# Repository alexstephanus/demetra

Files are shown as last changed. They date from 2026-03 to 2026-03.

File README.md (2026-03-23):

# Demetra
Demetra is a low-cost, local-first hydroponic controller.  It manages your system's pH, nutrient, and ORP levels, runs fertigation cycles, and can keep you reservoir topped up from an external water line or tank.

It reads the following set of sensors:
 - pH
 - ORP
 - Conductivity/TDS
 - Temperature

Using these sensors and the 6 supported peristaltic dosing pumps, it keeps your reservoir in the optimal range for plant growth.  Additionally, its 4 configurable DC outlets can drive fertigation cycles, stir treatment solutions into your reservoir, or drive general-purpose outlets.  It lets us 

It's built using off-the-shelf components, and designed end-to-end for ease of assembly and operation.  You can view assembly and setup docs [here](https://alexstephanus.github.io/demetra).

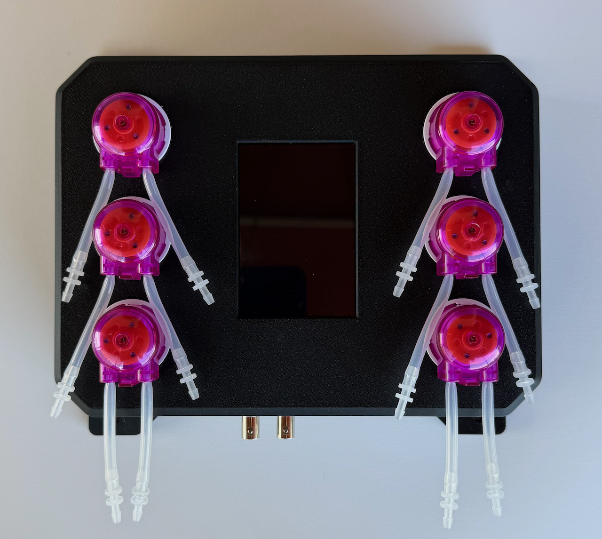
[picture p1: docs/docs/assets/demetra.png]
Here's what it looks like!


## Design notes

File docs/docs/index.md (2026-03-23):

# Demetra

You got into hydroponics because you care about what you're growing, not because you're passionate about pH and TDS levels.  Demetra takes care of that for you, freeing you up to focus on what's important: your plants.

Demetra is a low-cost, local-first, subscription-free hydroponic garden controller.
It provides hassle-free management of your system's pH, nutrient, and ORP levels.  Additionally, it can drive watering schedules and automatically top up your reservoir from a water line or external tank.
Demetra is built almost exclusively with off-the-shelf parts and components.  The parts that _are_ custom are explicitly designed to be fabricated as easily as possible:

- Motherboard:  Designed to be hand-populated, with primarily 0805 passives and SOIC-package ICs.  Any circuit board manufacturer should be able to fabricate the bare PCB, and you can populate it yourself.
- Enclosure:  240mm x 210mm x 65mm, which fits many consumer 3D printers.

<div class="grid cards" markdown>

- Demetra

</div>

## What it does

Demetra continuously monitors your system's pH, nutrient, and ORP levels, and adjusts them as needed to maintain optimal growth conditions.

Additionally, the system has 4 configurable DC outlets, which can be used for the following:

- Fertigation pumps, which run on a user-defined schedule
- Stir pumps, which are triggered to run after a treatment solution is added (e.g. pH down or nutrients), mixing your reservoir to ensure a tight feedback loop
- Solenoid valves, which can be used in conjunction with the water-level sensor to top up your reservoir from a water line
- General-purpose outlets, which are scheduled like fertigation pumps

Its local-first UI means that you can configure it using the onboard screen, no need for a subscription.

## What it doesn't do

Demetra's primary focus is reservoir control and fertigation management.  It does not try to do:

  - Plant health monitoring: It should free you up to pay more attention to your plants, but it won't do that for you.
  - Lighting, humidity, or other environmental control.  You could theoretically get by using general-purpose outlets and an external relay, but that's out of Demetra's wheelhouse.
  - Reservoir temperature control: Demetra does monitor your reservoir's temperature, but it uses that information to control your reservoir's pH and nutrient levels.

## Building it

For more information on how to build this project, see the [build guide](build_guide/what_you_need.md).
Outside of PCB assembly and enclosure printing time, assembly and initial setup should take a few hours.

## Cost

It costs about $400 to build, excluding sensors.

- Motherboard: $230: $100 shipped for fabrication of the bare PCB from JLCPCB, $130 for components from digikey (other suppliers might charge different prices).
- Enclosure: 500g of your chosen filament (call it $10), and heat-set inserts (~$10 for a set on Amazon, less from AliExpress)
- Peristaltic pumps: $80 shipped for 6 off of AliExpress, and JST pigtails are cheap if you throw in that order as well.
- Screen: $20 from either Amazon or AliExpress
- Sensors: Budget-dependent, on the low end you're looking at $20 for a pH probe, $20 for a conductivity probe, $30 for an ORP probe, and $5 for a 10k NTC thermistor.

Links to specific parts can be found in [What You Need](build_guide/what_you_need.md#part-purchase-links).

## Roadmap:
There are some features that currently have hardware support, but aren't handled yet on the software side:

- [ ] Plumb the external Digital I/O pin through in software to allow monitoring of an external flood sensor.  
- [ ] External I2C integration to ingest data from miscellaneous sensors.  The hardware configuration has been confirmed to work, but there isn't currently software support for using it.
- [ ] WiFi and MQTT support.  The ESP32 hardware supports this, but it's not yet built out.  This would allow for remote configuration and monitoring, as well as the ability to set up healthchecks, dashboards, and notifications on warnings and errors.
- [ ] Support for multiple treatment solutions of the same type, .
- [ ] The CAN and RS485 hardware is currently totally untested.

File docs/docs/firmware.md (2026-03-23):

# Firmware

## Overview

Demetra's firmware is written in Rust, targeting the ESP32-S3 microcontroller. It uses the ESP-HAL ecosystem with the Embassy async runtime, and a Slint-based GUI for the touchscreen display.

The firmware source lives in the `firmware/` directory of the repository, organized as a Cargo workspace:

- **`chip/`** — the main ESP32-S3 application that runs on hardware
- **`lib/`** — shared business logic and UI components, testable on a host machine
- **`simulation/`** — a desktop simulation of the UI (no hardware required)

## Try the UI (No Toolchain Required)

If you just want to see the interface, you can run the simulation in Docker:

```bash
cd firmware
docker build -f Dockerfile.sim -t demetra-sim .
docker run --rm -p 6080:6080 demetra-sim
```

Then open [http://localhost:6080/vnc.html](http://localhost:6080/vnc.html) in your browser.

## Toolchain Setup

To build and flash the firmware onto an ESP32-S3, you'll need the Rust ESP toolchain.

### 1. Install Rust

If you don't already have Rust installed, you can go to the [rust-lang installation instructions](https://rust-lang.org/tools/install/) and follow the installation instructions.

This project also uses the standard nightly toolchain for host-side builds (tests, simulation), you can install it :

```bash
rustup install nightly
rustup component add rust-src --toolchain nightly
```

### 2. Install the ESP Toolchain

`espup` manages rust's the `esp` toolchain, which includes the custom LLVM backend needed for the ESP32-S3's Xtensa architecture.
To set that up, head to [the espup repository](https://github.com/esp-rs/espup) and follow the installation instructions.

### 3. Install espflash

[espflash](https://github.com/esp-rs/espflash/blob/main/espflash/README.md) is used to flash firmware onto the board and open a serial monitor.

## Building & Flashing

Connect the ESP32-S3 board via USB (J52) or a UART converter (J51), then, from inside the project's root directory, run:

The USB connection does _not_ supply power to the board, so if you're flashing using a USB cable, you'll need to plug in the power supply as well.

```bash
cd firmware
cargo +esp flash-chip
```

This builds the firmware in release mode and flashes it to the connected board.

### Other Useful Commands

```bash
# Build without flashing
cargo +esp build-chip-release

# Check for compilation errors (faster than a full build)
cargo +esp check-chip

# Run unit tests (host machine, no hardware needed)
cargo unit-test

# Run the desktop simulation outside of Docker (this will just pop up a window with the simulated UI)
cargo sim
```

## After Flashing

Once the firmware is flashed, head over to [Setup](build_guide/setup.md) for initial configuration, sensor calibration, and pump setup.

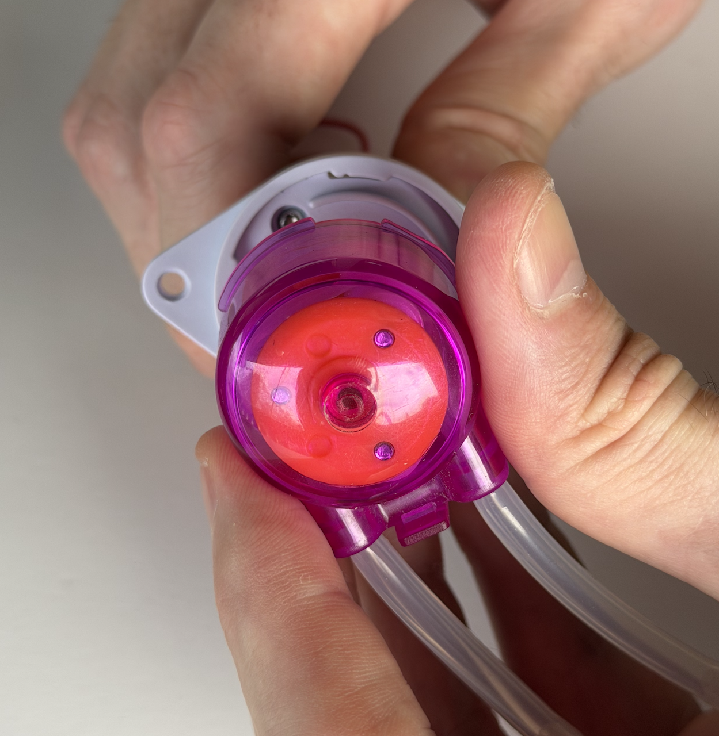
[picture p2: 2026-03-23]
docs/docs/assets/pump_mid_head_removal.png

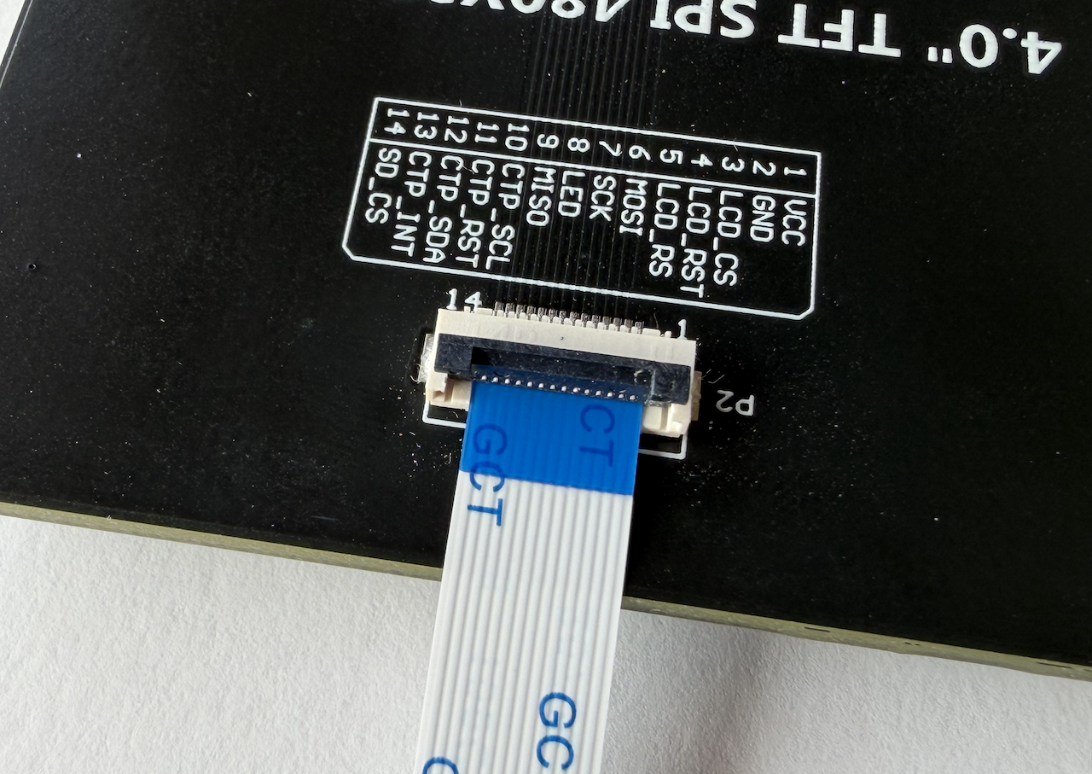
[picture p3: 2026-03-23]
docs/docs/assets/screen_cable_unlocked.png

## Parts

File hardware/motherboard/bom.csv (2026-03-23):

Reference | Value | DNP | Manufacturer_Part_Number
J51,J53,J54,J56,J201,JP51,JP52,TP1,TP2,TP3,TP4,TP5,TP6,TP7,TP8 | -- mixed values --
J52 | USB_B_Micro |  | 1051330011
C153 | 470u |  | 865080562016
C104,C105,C106,C107 | 1n |  | 885012207060
C27,C36,C45 | 1u |  | 12063C105KAT2A
C24,C28,C33,C37,C42,C46 | 1n |  | 12065C102KAT2A
U103 | ADS1015IDGS |  | ADS1015IDGSR
U13,U14,U15 | AMC3336 |  | AMC3336DWER
U152 | 3V3 Switching Reg |  | AP63203WU-7
J101,J102,J103,J104,J105,J106 | JST |  | B2B-XH-A
B201 | BH-25C-1 |  | BH-25C-1
C25,C26,C34,C35,C43,C44 | 1n |  | C0603C102K5RACTU
C10,C12,C13,C14,C17,C19,C23,C29,C32,C38,C41,C47 | 100n |  | C0603C104K5RACAUTO
C205,C206 | 4.7p |  | C0805C479D3HACTU
C151 | 22u |  | C2012X5R1V226M125AC
C21,C30,C39 | 100n |  | C3216NP01H104J160AA
R120,R123,R126,R129 | 0.02 |  | CFN1206-FX-R020ELF
C22,C31,C40 | 1u |  | CGA3E1X7R1E105K080AC
C53,C157,C159,C160,C202 | 22u |  | CL21A226MQQNNNG
C1,C2,C3,C4,C5,C6,C7,C8,C9,C11,C15,C16,C18,C20,C51,C52,C54,C101,C102,C103,C108,C109,C111,C112,C114,C152,C154,C155,C158,C201,C203,C204 | 100n |  | CL21B104KACNFNC
C110,C113,C115,C156 | 10u |  | CL21B106KOQNNNG
J2,J3 | CONBNC002 |  | CONBNC002
R67,R68,R71,R74,R75,R77,R78,R85,R101,R108,R110,R112,R114,R116,R118,R121,R124,R127,R151,R202,R203 | 220 |  | CRCW0805220RJNEA
R56,R58,R88,R102,R109,R111,R113,R115,R117,R119,R122,R125,R128,R152,R153,R154,R201,R206 | 10k |  | CRCW080510K0JNEA
R51,R52,R53,R54,R55,R57,R59,R60,R65,R66,R70,R72,R73,R79,R80,R81,R82,R83,R84 | 22 |  | CRCW080522R0FKEA
D62 | TVS |  | DESD12VL2BTQ-7
D1,D2,D3,D4,D51,D54,D55,D56,D57,D58,D59,D60,D61,D201 | TVS |  | DESD5V0L2BTQ-7
L152 | 4.7uH |  | DR73-4R7-R
U52 | TVS |  | DT1042-04TS-7
R86 | 1K |  | ERA-6AEB102V
R69,R76,R87,R204,R205 | 2K2 |  | ERA-6AEB222V
R21,R24,R27 | 47k |  | ERA-6AEB473V
D52,D53 | D_TVS_Dual_AAC |  | ESD752DBZ
U202 | ESP32-S3-WROOM-1-N16R8 |  | ESP32-S3-WROOM-1-N16R8
J61 | Screen |  | FFC2B35-14-T
K151 | G5LE-1 |  | G5LE-1 DC9
U101 | INA4180 |  | INA4180A3IPWR
Q101,Q102,Q103,Q104,Q105,Q106,Q107,Q108,Q109,Q110,Q151,Q152 | MOSFET |  | IRLML6344TRPBF
R103 | 0.05 |  | KDV08FR050ET
J151 | Barrel_Jack_Switch |  | KLDLX-0202-A
U1,U2,U11 | Opamp_Dual |  | LMP2232BMAE/NOPB
U151 | ~ |  | LMR51606YDBVR
D152 | LED |  | LTST-C171GKT
U5 | ISO7320C |  | MAX22420FASA+
U203 | MCP7940N-xSN |  | MCP7940NT-I/SN
U201 | MCP23017_SO |  | MCP23017-E/SO
U3,U6,U7 | MCP1501-10xCH |  | MCP1502T-10E/CHY
U153,U154 | ~ |  | NID5100-Q100H
SW201,SW202 | -- mixed values -- |  | PTS636 SM43 SMTR LFS
R104,R105,R106,R107 | 51 |  | RC0805FR-0751RL
R62,R63 | 10 |  | RC0805FR-1010RL
R61,R64 | 120 |  | RC0805FR-07120RL
R6,R8,R9,R13,R15,R16,R157 | 1K |  | RG2012P-102-B-T5
R3,R7,R10,R11,R12,R14,R156 | 10k |  | RG2012P-103-B-T5
R1,R2,R4,R5,R17,R18,R19,R20,R22,R23,R25,R26,R155 | 100k |  | RG2012P-104-B-T5
CR101,CR102,CR103,CR104,CR105,CR106,CR107,CR108,CR109,CR110,CR151 | FLYBACK |  | SBR3U40S1FQ-7
Y201 | Crystal |  | SC32S-7PF20PPM
D151 | SMCJ33A |  | SMCJ33A
U12,U102 | 4052 |  | SN74LV4052ADR
U4 | 74LVC1G86 |  | SN74LVC1G86DBVR
J55,J58 | Screw_Terminal_01x03 |  | TB0011-350-03BE
J107,J108,J109,J110 | 5.08x02 Pluggable Screw |  | TBP01R1-508-02BE
J1,J4 | 3.50x02 Pluggable Screw |  | TBP03R1-350-02BE
J59,J62 | Screw_Terminal_01x03 |  | TBP03R1-350-03BE
J60 | Screw_Terminal_01x04 |  | TBP03R1-350-04BE
U51 | TCAN330 |  | TCAN330DR
U53 | THVD1420D |  | THVD1450DR
U10 | TS3A24159DGSR |  | TS3A24159DGSR
U8,U9 | TS3A44159PWR |  | TS3A44159PWR
L151 | 47uH |  | VLS6045EX-470M

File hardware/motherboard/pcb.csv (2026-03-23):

Reference | Value | Qty | DNP | Manufacturer_Part_Number | Description
J1,J3 | Conn_01x01_Pin | 2 |  |  | Generic connector, single row, 01x01, script generated
F1,F2,F3 | Fuse | 3 |  | 3404.2422.11 | Fuse
C7 | 220u | 1 |  | 865080345012 | 865080345012
C29,C30,C48,C50,C51,C54,C68,C69,C70,C71 | 1n | 10 |  | 885012207060 | Unpolarized capacitor
U3,U10,U16 | 74LVC1G3157GV,125 | 3 |  | 74LVC1G3157GV,125 | SPDT Analog Switch, Low-Voltage CMOS
U18 | ADS1015IDGS | 1 |  | ADS1015IDGSR | Ultra-Small, Low-Power, I2C-Compatible, 3.3-kSPS, 12-Bit ADCs With Internal Reference, Oscillator, and Programmable Comparator, VSSOP-10
U24,U25 | AMC1336DWVR | 2 |  | AMC1336DWVR
U7,U22 | AMC3336 | 2 |  | AMC3336DWER | Reinforced Isolated Delta-Sigma Modulator With Integrated DC/DC Converter, SOIC-16W
U4 | 3V3 Switching Reg | 1 |  | AP63203WU-7 | 3v3 Switching Regulator
J_DOSE_1,J_DOSE_2,J_DOSE_3,J_DOSE_4,J_DOSE_5,J_DOSE_6 | JST | 6 |  | B2B-XH-A | Generic connector, single row, 01x02, script generated
B1 | BH-25C-1 | 1 |  | BH-25C-1 | Single-cell battery
C8,C42,C60,C61,C62,C63 | 2.2u | 6 |  | C2012X7R1H225K125AC | Unpolarized capacitor
C2,C5,C11,C12 | 22u | 4 |  | CL21A226MQQNNNG | CL21A226MQQNNNG
C1,C3,C4,C6,C10,C16,C18,C24,C25,C26,C28,C33,C35,C36,C37,C38,C41,C45,C47,C49,C55,C58,C59,C64,C65,C66,C67,C72,C73,C74,C75 | 100n | 31 |  | CL21B104KACNFNC | MLCC
C13,C27,C31,C46,C53,C57 | 1u | 6 |  | CL21B105KAFNNNE | Unpolarized capacitor
C9,C23 | 10u | 2 |  | CL21B106KOQNNNG | Unpolarized capacitor
C43,C44,C52,C56 | 4.7n | 4 |  | CL21B472KBANNNC | Unpolarized capacitor
C40 | 47uF | 1 |  | CL32A476KOJNNNE | Unpolarized capacitor
J_pH1,J_pH3 | CONBNC002 | 2 |  | CONBNC002 | CONBNC002
R3,R5,R6,R9,R11,R13,R15,R17,R18,R19,R25,R27,R30,R34,R53,R61 | 220 | 16 |  | CRCW0805220RJNEA | Resistor
R7,R8,R10,R12,R14,R24,R26,R32,R35,R40,R49,R51,R54,R55,R56 | 10k | 15 |  | CRCW080510K0JNEA | Resistor
Q2,Q3,Q4,Q5,Q6,Q7,Q10,Q11,Q12 | MOSFET | 9 |  | DMG1012UW-7 | -- mixed values --
Q1,Q8,Q9 | MOSFET | 3 |  | DMN3404L-7 | DMN3404L-7
L1 | 4.7uH | 1 |  | DR73-4R7-R | Inductor
R52 | 1K | 1 |  | ERA-6AEB102V | Resistor
R20,R21,R22 | 2K2 | 3 |  | ERA-6AEB222V | Resistor
R48 | 174K | 1 |  | ERJ-6ENF1743V | Resistor
U2 | ESP32-S3-WROOM-1-N16R8 | 1 |  | ESP32-S3-WROOM-1-N16R8 | ESP32-S3-WROOM-1-N16R8
U5 | INA4180 | 1 |  | INA4180A3IPWR | Low-Power, Quad-Operational Amplifiers, DIP-14/SOIC-14/SSOP-14
U12 | Isolator | 1 |  | ISO7720FDR
R37 | 0.05 | 1 |  | KDV08FR050ET | Resistor
J2 | Barrel_Jack_Switch | 1 |  | KLDLX-0202-A | DC Barrel Jack with an internal switch
C14,C15,C17,C19,C20,C21,C22,C32,C34 | 1u | 9 |  | LMK212BJ105KG-T | Unpolarized capacitor
U23 | LMR51430 | 1 |  | LMR51430XDDCR | 4.5-V to 36-V, 3-A synchronous buck converter with 40-µA IQ, SOT-23-6
3V3_D2,12V_D1 | LED | 2 |  | LTST-C171GKT | Light emitting diode
R16,R36,R50 | 0.01 | 3 |  | LVT12R0100FER | Resistor
U17 | MCP7940N-xSN | 1 |  | MCP7940NT-I/SN | Real-Time Clock, I2C, Battery Backup, SOIC-8
U11 | MCP23017_SO | 1 |  | MCP23017-E/SO | 16-bit I/O expander, I2C, interrupts, w pull-ups, SOIC-28
U13 | MCP1501-18xCH | 1 |  | MCP1501T-18E/CHY | 1.8V, 0.1%, 20mA, Precision Voltage Reference, SOT-23-6
L5 | 22uH | 1 |  | NS10165T220MNA | Inductor
U15 | NXE1S0303MC | 1 |  | NXE1S0303MC-R13 | 1W 3.3V to 3.3V 303mA DC-DC Converter with 3kV isolation
BOOT1,RESET1 | -- mixed values -- | 2 |  | PTS636 SM43 SMTR LFS | -- mixed values --
R1,R4,R33,R38,R39,R41,R42,R43,R45,R46,R47,R57,R58,R59,R60 | 51 | 15 |  | RC0805FR-0751RL | Resistor
R23,R28,R29,R31,R44 | -- mixed values -- | 5 |  | RG2012P-103-B-T5 | Resistor
R2 | 510 | 1 |  | RMCF0805JT510R | Resistor
U1,U21 | RS8522XK | 2 |  | RS8522XK | Dual Rail-to-Rail Input/Output Operational Amplifier, DIP-8/SOIC-8/VSSOP-8
CR1,CR2,CR3,CR4,CR5,CR6,CR7,CR8,CR10 | FLYBACK | 9 |  | SBR3U40S1FQ-7 | 1000V 1A General Purpose Rectifier Diode, DO-41
Y1 | Crystal | 1 |  | SC32S-7PF20PPM | Two pin crystal
L2 | 15uH | 1 |  | SRN2012T-150K | Inductor
J_SCREEN1 | Screen | 1 |  | SSQ-114-03-T-S | Generic connector, single row, 01x14, script generated
J_CFG_1,J_CFG_2,J_CFG_3 | 5.08x02 Pluggable Screw | 3 |  | TBP02R1-381-02BE | Generic screw terminal, single row, 01x02, script generated (kicad-library-utils/schlib/autogen/connector/)
J_EC1,J_TEMP1 | 3.50x02 Pluggable Screw | 2 |  | TBP03R1-350-02BE | Generic screw terminal, single row, 01x02, script generated (kicad-library-utils/schlib/autogen/connector/)
J_DIG_1,J_FLOAT_1 | Screw_Terminal_01x03 | 2 |  | TBP03R1-350-03BE | Generic screw terminal, single row, 01x03, script generated (kicad-library-utils/schlib/autogen/connector/)
J_I2C1 | Screw_Terminal_01x04 | 1 |  | TBP03R1-350-04BE | Generic screw terminal, single row, 01x04, script generated (kicad-library-utils/schlib/autogen/connector/)
U8,U19,U20 | TPS60400DBV | 3 |  | TPS60400DBVR | Unregulated 60-mA Charge Pump Voltage Inverter with Variable Switching Frequency 50 kHz - 250 kHz, SOT-23-5
U14,U30 | TPS7A0522PDBZ | 2 |  | TPS7A0522PDBZR | 200-mA Ultra-Low-Iq LDO, 2.2V, SOT-23-3

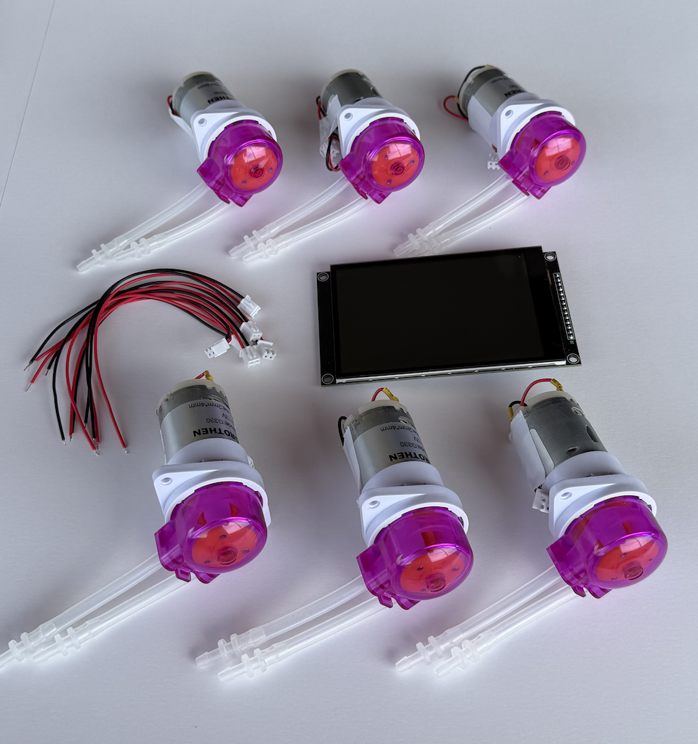
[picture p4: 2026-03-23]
docs/docs/assets/assembly_parts.png

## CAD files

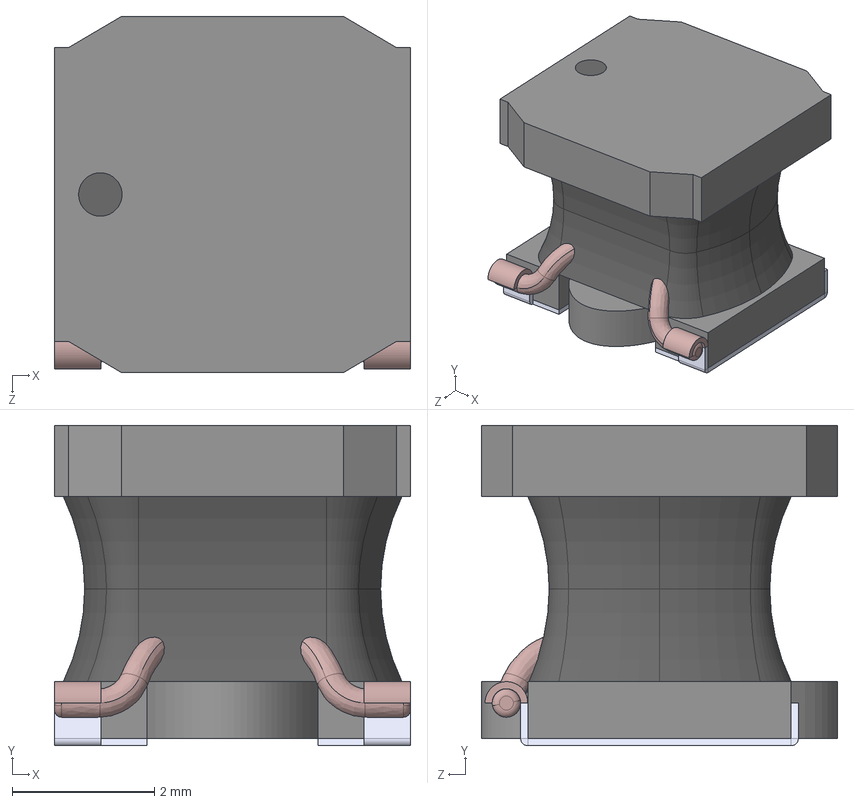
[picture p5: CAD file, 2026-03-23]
hardware/motherboard/components/VLS5045EX-4R7M.step
5.00 x 4.50 x 5.00 mm

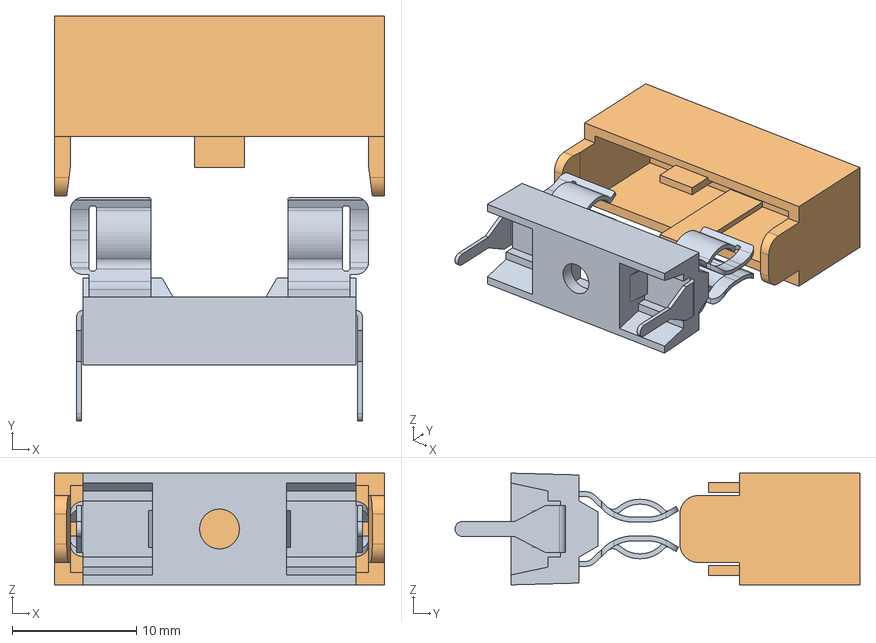
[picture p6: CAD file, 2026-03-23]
hardware/motherboard/components/696101000002.step
26.6 x 32.6 x 9.00 mm

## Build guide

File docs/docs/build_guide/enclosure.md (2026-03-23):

# Enclosure Assembly

This guide covers printing and assembling the 3D-printed enclosure.

## Before You Print

Before committing to printing the full enclosure, it's recommended to print the fit testers to verify compatibility with your specific printer calibration and parts:  

- [ ] Screen fit tester
- [ ] Pump fit tester

**Tip:** Use scarf seams if your slicer supports them.  Otherwise, you might need to trim seam bumps out of critical holes.

The screen and pump should fit snugly into these holders.  Adjust your print settings if you're not able to get a good fit with the fit testers.  Failing that, you can try tweaking some design parameters in FreeCAD to get a better fit.

## Parts to Print

- [ ] 1x Case body
- [ ] 1x Case back
- [ ] 2x Pump plates
- [ ] 2x Screen holders

  NOTE: the enclosure body shown in most of these assembly photos has 2 of its sides chopped off.  Additionally, in later assembly photos the pump plates and screen holders are printed in a white filament.  These are simply to make certain steps easier to see -- your enclosure body should have all 4 sides, and there's no need to use a different filament for internal printed parts when you're building this.

<div class="grid cards" markdown>

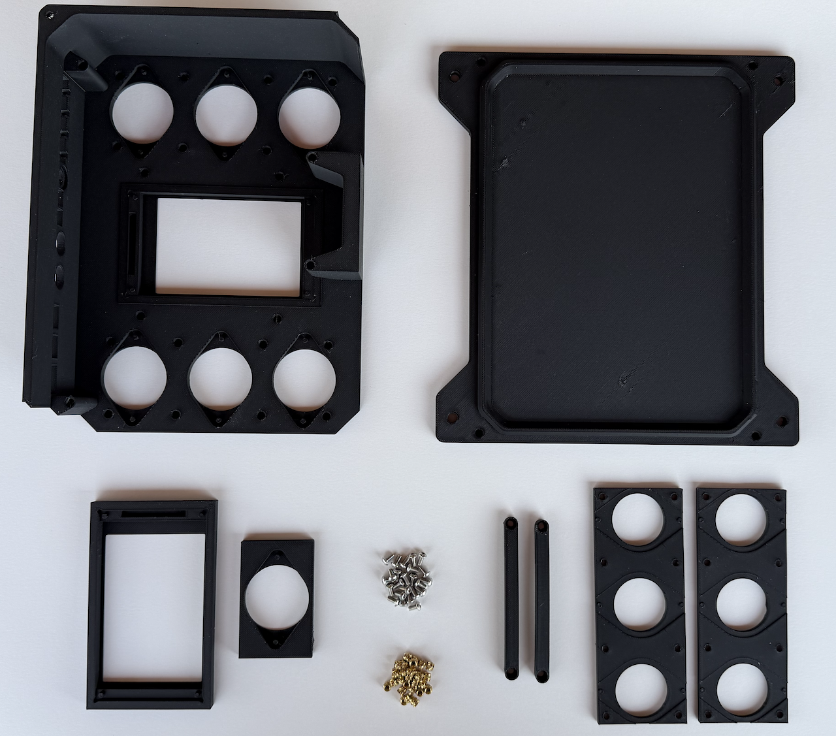
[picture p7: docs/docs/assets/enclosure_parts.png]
All printed parts
- 

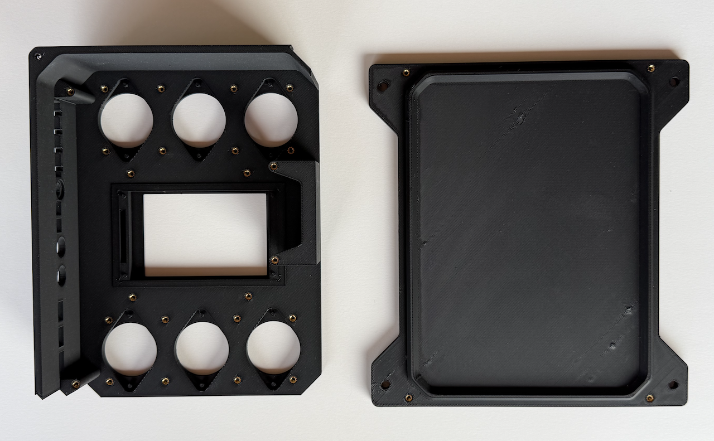
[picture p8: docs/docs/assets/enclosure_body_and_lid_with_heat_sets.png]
Prepared Enclosure
- 

</div>

Tree supports work well for the connector holes on the bottom wall of the enclosure, as well as overhanging screw holes.  As with the fit testers, use scarf seams if you can.

## Heat-Set Insert Installation

After printing, install the M3x5x4 heat-set inserts:

- [ ] Heat soldering iron to appropriate temperature for the material you used
- [ ] Install 28x M3x5x4 heat-set inserts into designated holes

    - [ ] Enclosure Body: 24 inserts
    - [ ] Enclosure Back: 4 inserts

<div class="grid cards" markdown>

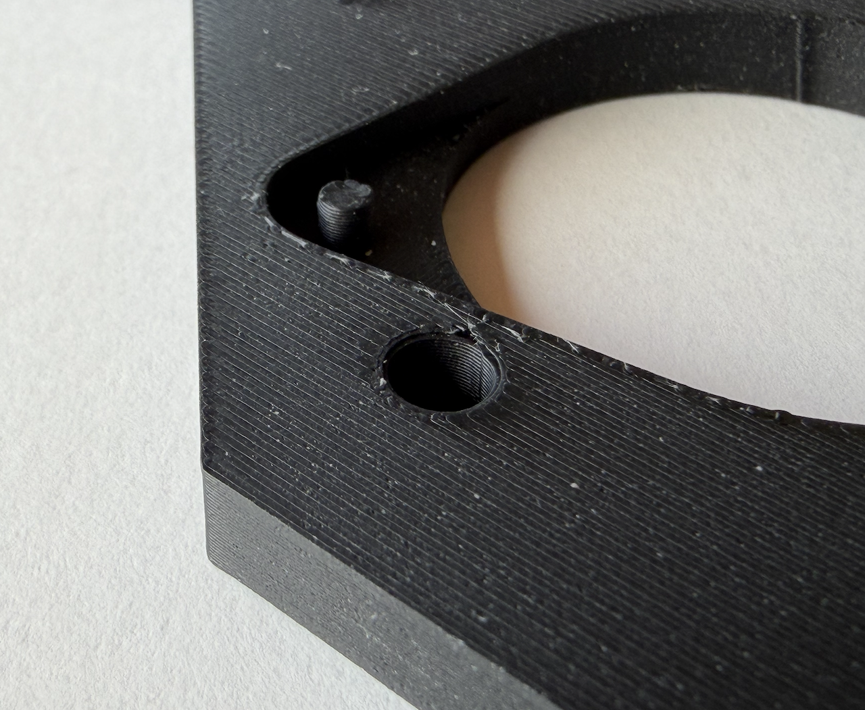
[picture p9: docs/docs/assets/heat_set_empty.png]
Heat-set insert in hole
- 

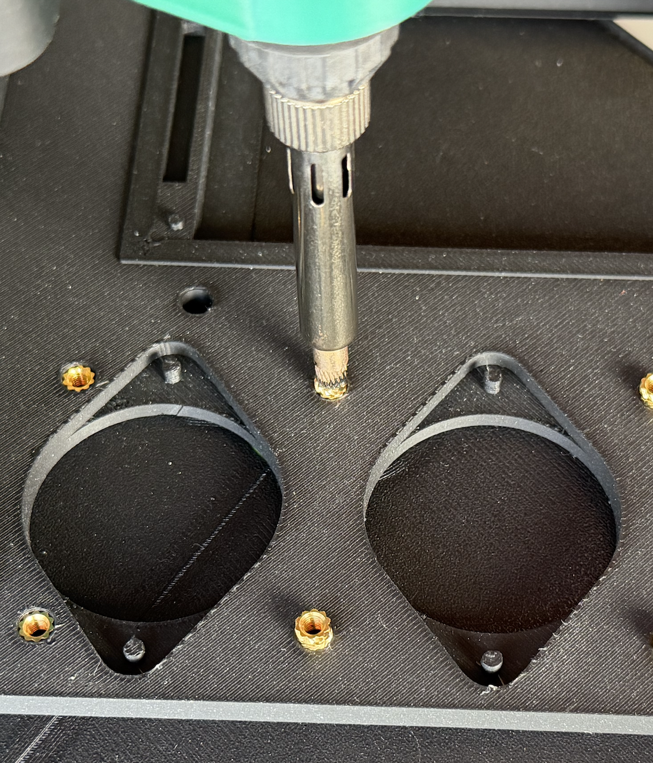
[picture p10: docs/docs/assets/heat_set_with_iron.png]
Heat-set insert insertion
-  

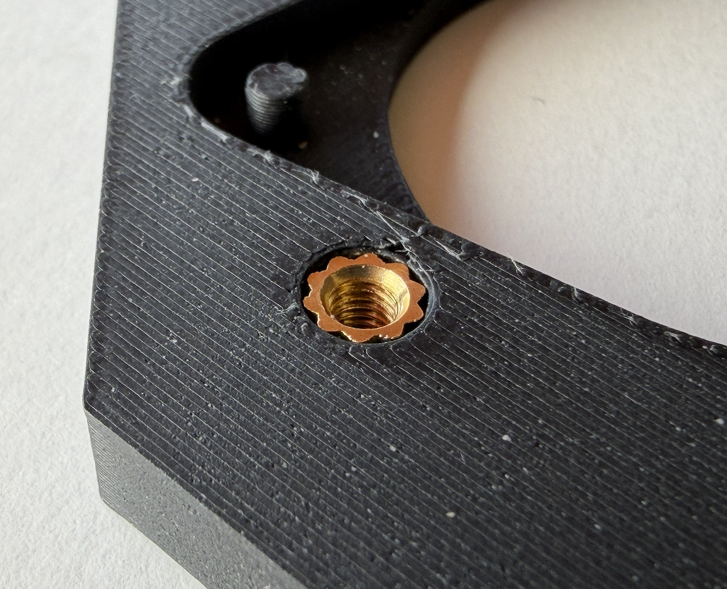
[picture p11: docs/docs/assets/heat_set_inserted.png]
Heat-set insert fully in
- 

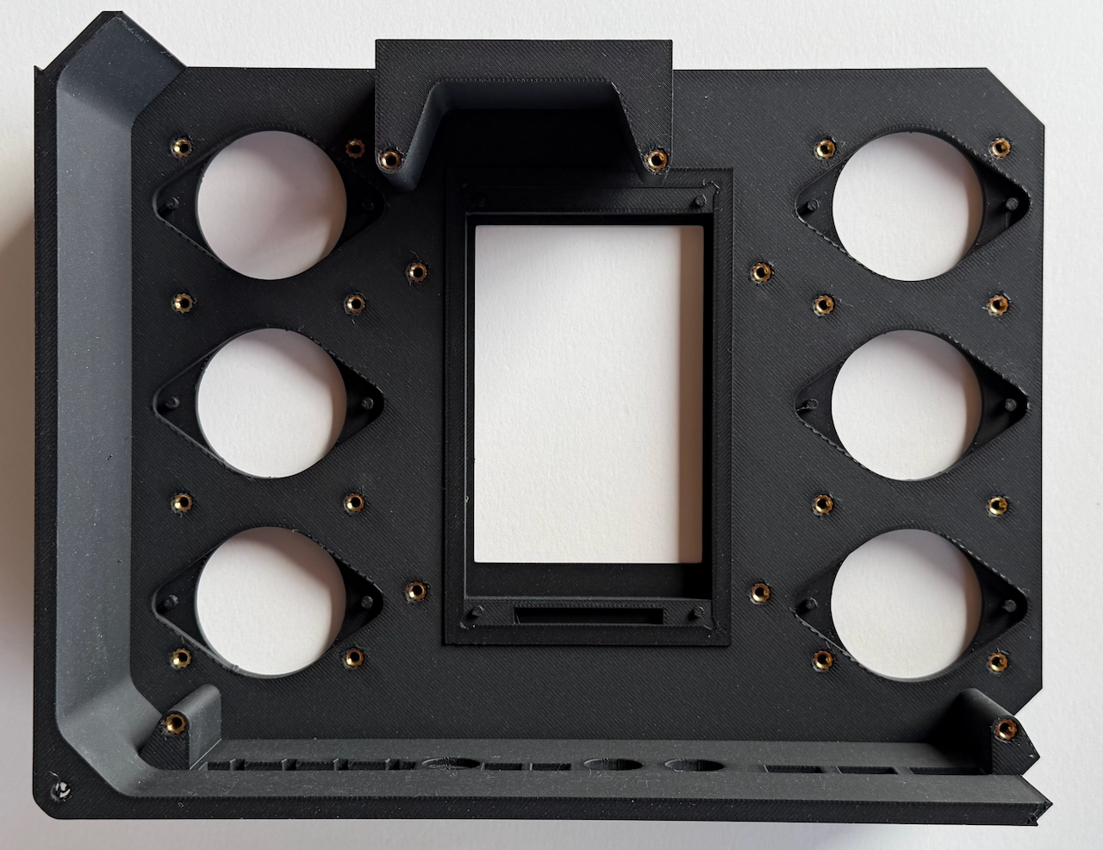
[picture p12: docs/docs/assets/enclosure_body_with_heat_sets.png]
All heat-set inserts in place
- 

</div>

**Tip:** Use an M3 heat-set insert tip if possible.  It makes for easier installation, plus it saves you from having to clean melted, burned plastic off of your soldering iron's tip.

## Fit Verification

Before proceeding to final assembly, verify the following fits:

- [ ] LCD screen fits properly in its mounting location
- [ ] Peristaltic pumps fit in their respective mounting holes
- [ ] Bare or populated PCB fits in case body
- [ ] All heat-set inserts are properly seated and threads are clear
- [ ] Enclosure back fits cleanly onto enclosure body, and the two halves screw together cleanly

## Next Steps

Once the enclosure is complete and fit-checked, proceed to [Final Assembly](assembly.md).

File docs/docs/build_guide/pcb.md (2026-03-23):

# PCB Assembly

This section covers populating and reflowing the motherboard, as well as attaching through-hole components. It doesn't get into the nuts and bolts of SMD soldering.  If you haven't done this before, it is totally possible to learn! You should watch a few tutorials at a minimum and, additionally, consider using any of the litany of surface-mount practice boards to familiarize yourself with the process before diving into assembling this motherboard.

## Before You Start

**Required Tools:**

- [ ] Surface-mount soldering equipment (see [What You Need](what_you_need.md))
- [ ] Soldering iron, flux, and solder wick
- [ ] 99% isopropyl alcohol for cleanup
- [ ] Multimeter for testing
- [ ] Magnification device (Magnifier visor, stereo microscope, or magnifying lamp) to accurately place components

**Required Parts:**

- [ ] Bare PCB
- [ ] Solder paste stencil
- [ ] Electronic Components

## SMD Component Assembly

### **Note:**
You shouldn't leave un-reflowed solder paste on the PCB.  So, if you're applying solder paste with a stencil, make sure you have enough time to populate all components in one go.  This takes me about 3 hours by hand, and I know where everything goes.  So, be advised, it'll take a while. You can deal with THT components later, in multiple batches, or one a day for a month if you so desire.

### 1. Apply Solder Paste

- [ ] Align stencil over PCB
- [ ] Apply solder paste with squeegee
- [ ] Inspect paste application quality

### 2. Place Components

- [ ] Populate all surface-mount components.

**Important: Verify Polarized Component Orientation**

Before reflowing, double-check the orientation of these polarized components:

- [ ] Diodes (verify cathode markings are opposite the empty side of the rectangle)
- [ ] Electrolytic bulk capacitor (C153) should line up with the silkscreen marking
- [ ] ICs (verify pin 1 indicators match PCB silkscreen)

Also, you should ensure that there aren't any bare SMD pads.  If there are, go back and add the appropriate component there.

### 3. Reflow
- [ ] Place PCB in reflow oven.
- [ ] Run appropriate reflow profile for the solder paste you're using (Or wing it, if you're just using a toaster oven)
- [ ] Allow PCB to cool before handling.

### 4. Inspection for Bridging
Using magnification, carefully inspect all components, paying special attention to fine-pitch components:

**Components requiring extra attention:**

- [ ] U103: Current-sensing ADC
- [ ] U202: ESP32
- [ ] J52: Micro-USB connector
- [ ] J61: Screen connector
- [ ] U8, U9, U10: Analog switches for temperature & EC sensors

**Check for:**

- [ ] Solder bridges between pins
- [ ] Cold solder joints
- [ ] Tombstoned components
- [ ] Missing components

### 5. Rework (if needed)
- [ ] Apply flux to any bridged pins
- [ ] Use solder wick to remove excess solder
- [ ] Reflow individual components as needed

Once you're satisfied with your reflow quality, it's time to install through-hole components.

## Through-Hole Component Assembly

**Note:** Some through-hole components are installed on top of the PCB (The side you just populated).  All of the external connectors on the bottom of the PCB are installed on the underside of the PCB.

### 1. Install Through-Hole Components on Top of the PCB

Components to install:

- [ ] J55: CAN bus terminal
- [ ] J58: RS485 terminal
- [ ] J101-106: JST XH Connectors
- [ ] J51: Serial pin header
- [ ] K151: Relay
- [ ] J52: Micro-USB connector (the component should already be populated, but you have to solder the 3 through-hole pins to keep it in place.  The surface-mount pads alone won't stand up to unplugging a cable -- if you skip this step you'll rip the connector, and probably the pads, off of the board when you try to use it)

### 2. Install Through-Hole Components on Underside of PCB

**Note: Be precise here**
The tolerances on the enclosure openings are pretty tight, so you don't have a ton of wiggle room when soldering these connectors.  Ensure they're flush with the PCB and not askew.  It might help to solder a single pin of each connector, then insert the PCB into the enclosure, soldering the other pins once you're sure everything fits well.

- [ ] J107-110: Outlet terminals
- [ ] J151: DC Barrel Jack
- [ ] J1, J4: 2-pin EC & temperature sensor pluggable terminals
- [ ] J2, J3: BNC Connectors
- [ ] J59, J62: 3-pin Digital IO and Float Switch pluggable terminals
- [ ] J60: 4-pin external I2C pluggable terminal

### 3. Final Cleanup
- [ ] Clean any remaining flux with isopropyl alcohol, paying particular attention to the sensor sections.

## Visual Inspection Checklist

- [ ] All components placed and oriented correctly
- [ ] No solder bridges visible under magnification
- [ ] No cold solder joints
- [ ] All flux residue cleaned
- [ ] No damaged components

## Electrical Testing

Before proceeding to powering it up and flashing the firmware, perform some basic electrical tests:

### Power Supply Tests
- [ ] Using a multimeter, check for shorts between power and ground rails (should read open circuit)
  - [ ] Main power nets:
    - [ ] DC Input: the rectangular pad of the DC power jack (farthest from the edge of the board) is V_DC
    - [ ] 3.3V: This via is located on J201, just below the ESP32
    - [ ] 9V: This pin is located on J62
    - [ ] Main GND
  - [ ] Isolated sensor nets
    - [ ] pH
      - [ ] 3.3V: + via adjacent to U15
      - [ ] GND: - via adjacent to U15
      - [ ] 1V: This via is just above the pH BNC connector, near R1
    - [ ] ORP
      - [ ] 3.3V: + via just above the ORP BNC connector, to the left of U2
      - [ ] GND: - via just above the ORP BNC connector, to the left of U2
      - [ ] 1V: This via is just below C31, check for shorts here between the + and - vias
    - [ ] EC/Temperature
      - [ ] 3.3V: + via adjacent to U13
      - [ ] GND: - via adjacent to U13
      - [ ] 1V: The 1V via is just above the temperature sensor terminal block.

Once you're satisfied with a visual inspection and you've verified that there are no shorts on power rails, you can proceed to flashing the firmware and assembling the unit.

## Next Steps

Once the PCB is fully assembled and tested, proceed to [Enclosure Assembly](enclosure.md).

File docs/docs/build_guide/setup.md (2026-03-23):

# Setup

Okay, so you've got everything assembled, the firmware is flashed, and it boots without errors.  Everything looks good.  Now what?

## Initial configuration
Tap on the "Config" tab when your unit boots up.  You'll see a few options:

 - Tank size: Input the size of your reservoir.  This is used to calculate treatment solution dosage volumes.
 - Display Units: Set the temperature and conductivity to your desired display units.  By default it uses Celsius and uS/cm.
 - Time: Set the appropriate date, time, and time zone for your location.

## Sensor Setup & Calibration
Once you've got the basic device configurations done, you'll need to set up and calibrate whatever sensors you're using.  

### Plug in Your Sensors
For starters, plug in all the sensors you're planning on using.  The enclosure doesn't have any visual indications on the exterior of which sensors go where, so their locations are listed below.

- pH: The BNC terminal on the right
- ORP: The BNC terminal on the left
- Conductivity: The 2-pin pluggable terminal to the immediate left of the DC power jack
- Temperature: The 2-pin pluggable terminal to the immediate right of the BNC jacks

Note: conductivity and temperature sensors don't care about polarity, so no need to worry about which wire goes where in the screw terminal.  Just make sure that everything is plugged into the right input jack.

### Sensor Software Setup
Once they're all plugged in, enable and calibrate all the sensors you'll be using.  To enable and begin using a sensor, click the sensor's display in the "Status" tab to enable it, and use the "Change Allowed Range" button to set the minimum and maximum acceptable values for the sensor.  Once Demetra registers a reading that falls outside of the acceptable range, it will automatically take corrective action if possible.  Besides enabling the sensor and setting the range, different sensors require different setup and calibration steps:

  - [ ] Temperature: Demetra uses a 10k NTC thermistor, and you'll need to configure the beta value for your thermistor*. Do this first, since both pH and EC are affected by temperature, so to get the most calibrations and measurements possible you'll need to be able to measure temperature.  
  - [ ] pH: Calibrate the sensor using calibration solutions of known pH (Note: For the moment only 3-point calibration is supported)
  - [ ] Conductivity: Calibrate the sensor using a calibration solution of known conductivity.
  - [ ] ORP: Calibrate the sensor using a calibration solution of known ORP.

\* The beta value indicates how strongly the thermistor's resistance varies with temperature, and it's necessary to convert raw readings into a meaningful temperature measurement. This value should be available in the datasheet, spec, or listing for your thermistor -- Demetra works with any beta value, but it does need to know what that value is.

## Dosing Pump Calibration
Using inexpensive dosing pumps helps keep overall cost low, but the downside is that their flow rates can vary significantly from pump to pump.  But!  That variation can be accounted for to dial in the flow rate for a particular pump.  Calibrating your pumps lets Demetra take each pump's flow rate into account when calculating how long to run a pump to dose in a particular amount of treatment solution.  To calibrate a dosing pump, click the pump's icon in the "Pumps" tab, and use the "Calibrate" button to determine that particular pump's flow rate.  You'll need water and something to measure volume (or weight) precisely.  It's easiest to knock out all 6 pumps at the same time, then you don't need to worry about it again.

## Dosing Pump Setup
Demetra's dosing pumps are used to control your reservoir's pH, nutrient, and ORP levels.  They're automatically triggered when sensors detect measurements outside your acceptable range.  Demetra supports up to 6 dosing pumps, which can be configured with the following options:
  - pH Down: Added whenever your reservoir's pH needs to lowered
  - pH Up: Added whenever your reservoir's pH needs to be raised
  - Nutrients: Added whenever your reservoir's nutrient levels fall outside your configured range*
  - ORP Treatment: Added whenever your reservoir's ORP levels drop

To set up a dosing pump, click the pump's icon in the "Pumps" tab, and do the following:
  - Configure the treatment solution you're using, and the solution strength if you have it -- if not, you can measure the solution strength using the "One-off Measurement" function of the appropriate sensor, with the caveat that you may need to dilute the treatment solution to get an accurate reading.
  - (Optional) Rename the pump to something more descriptive

\* Right now, Demetra only supports using a single nutrient solution.  There's a roadmap item for supporting multiple nutrient solutions, mixing ratios, and scheduled ratio changes.  However, at the moment, you'll need to pre-mix them together into a single solution.

## Outlet Setup

**CAUTION: Outlets can source a maximum current of 3A**
This amperage can be distributed among outlets however you want.  Right now, software support for current monitoring and automatic shutoff isn't fully implemented, so it's up to you to make sure your outlets' loads don't exceed 3A combined.  If you need to drive a larger load than that, you can set up an external relay and hook it up to an outlet.

### Wire up an Outlet
To wire up an outlet, prep your wires for the screw terminal (either by crimping or by twisting and U-bending them), and then connect them to the terminal plug as shown below.  Red (left) is VCC, black (right) is GND.  Once you've tightened the screws to hold the wires in place, give them a gentle tug to make sure they're locked in place.

<div class="grid cards" markdown>

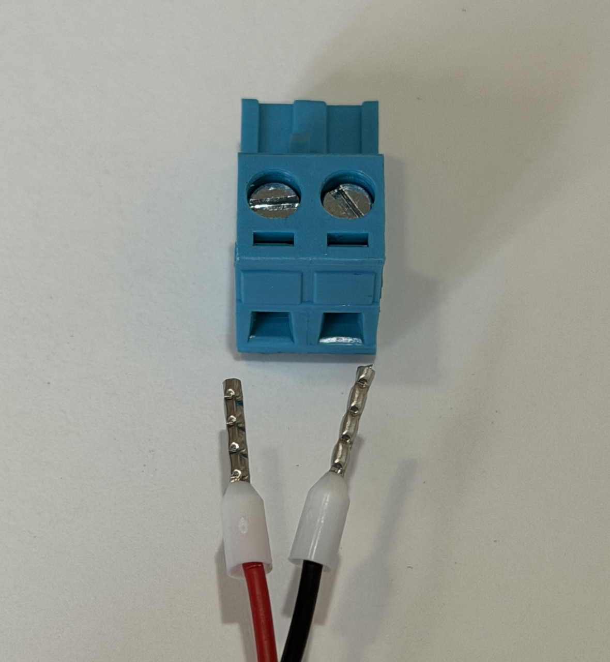
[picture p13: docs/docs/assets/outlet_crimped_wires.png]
Outlet wires crimped
- 

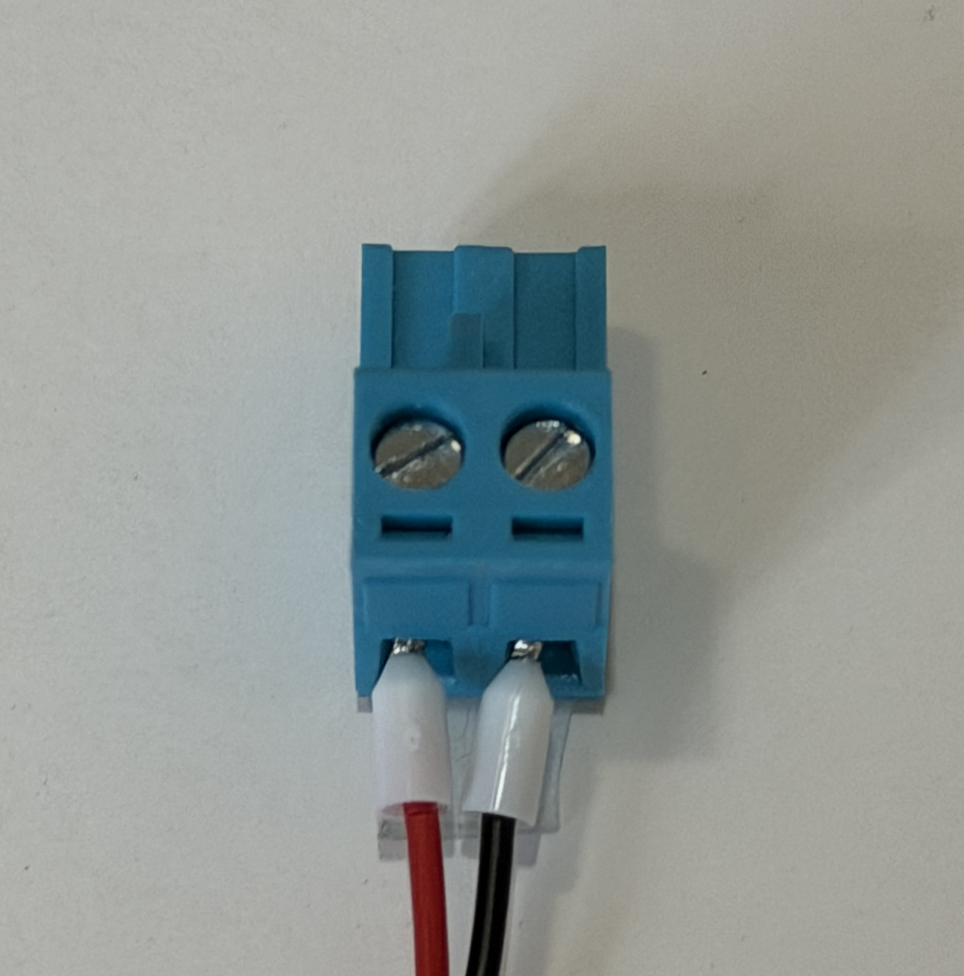
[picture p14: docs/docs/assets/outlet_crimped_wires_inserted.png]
Crimped outlet wires in screw terminal
-  

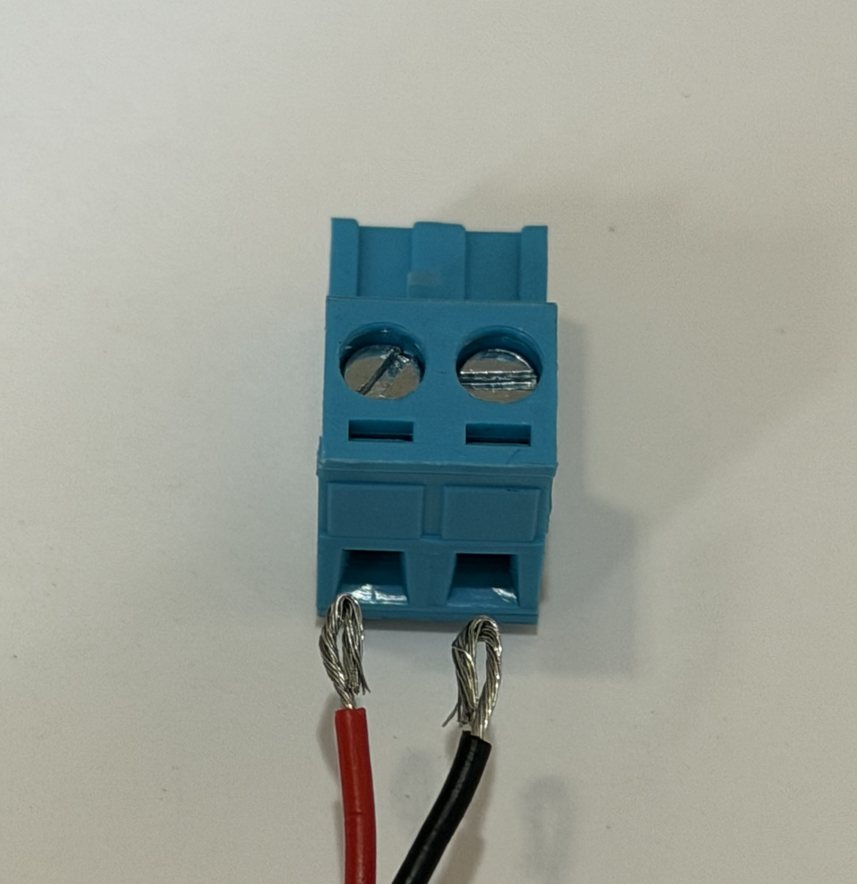
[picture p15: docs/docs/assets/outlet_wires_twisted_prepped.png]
Outlet wires twisted
- 

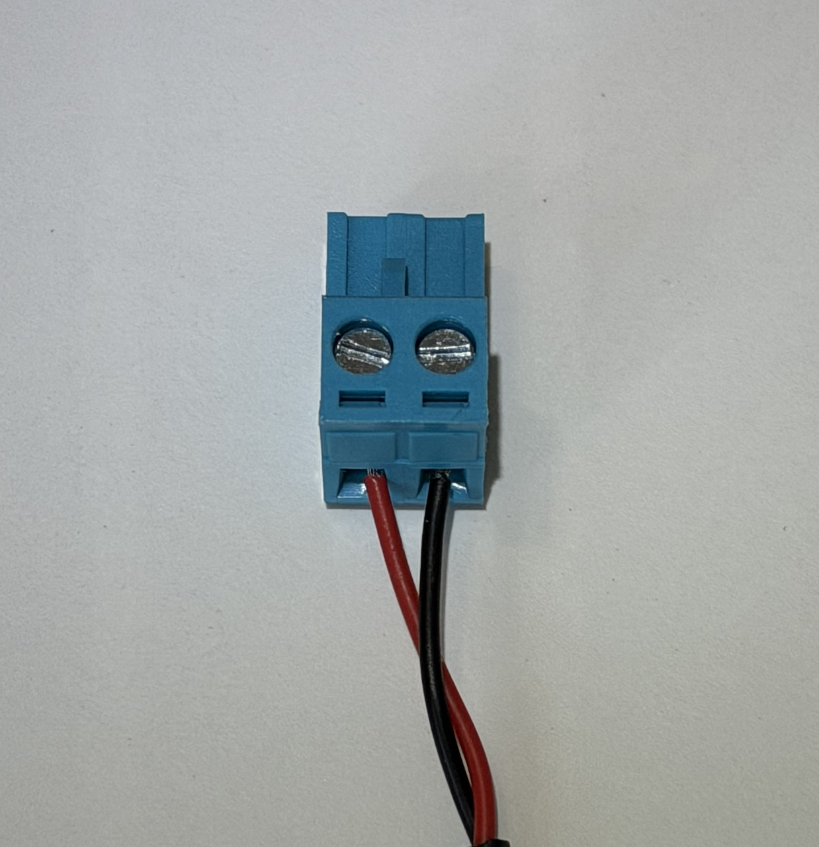
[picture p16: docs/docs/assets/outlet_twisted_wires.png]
Twisted outlet wires in screw terminal
- 

</div>

### Outlet Software Setup

To set up an outlet, click the outlet's icon in the "Outlets" tab.  Demetra supports up to 4 DC outlets, which can be used for any of the following:

  - Fertigation pumps: These run on whatever schedule you configure.
  - Solenoid valves: If you have a water line feeding your reservoir, demetra supports automatic top-up of your reservoir from the water line once the float switch is activated.
  - Stir pumps: Sits inside your reservoir, triggered to run after a treatment solution is added.  They're not strictly necessary, but they will make your dosing feedback loop much tighter, since they'll disperse treatment solutions evenly throughout your reservoir.
  - General-purpose outlets: This is a catchall category for anything besides a fertigation pump that you want to control.  They're scheduled exactly like fertigation pumps.

## Float Switch Wiring

Demetra expects your float switch to send a high voltage when the water level is low.  So, if you're using a mechanical float switch, it needs to be a normally-closed switch.  If you're using a capacitive float switch like the XKC-Y25-V, you need to ensure that its output is high when the water level is low.  The below image is the wiring for the XKC-Y25-V capacitive float switch: yellow is output, brown is VCC, and blue is GND.  In this case, the black wire (MODE) crimped to GND, so that the switch output goes high when it detects a low water level.

<div class="grid cards" markdown>

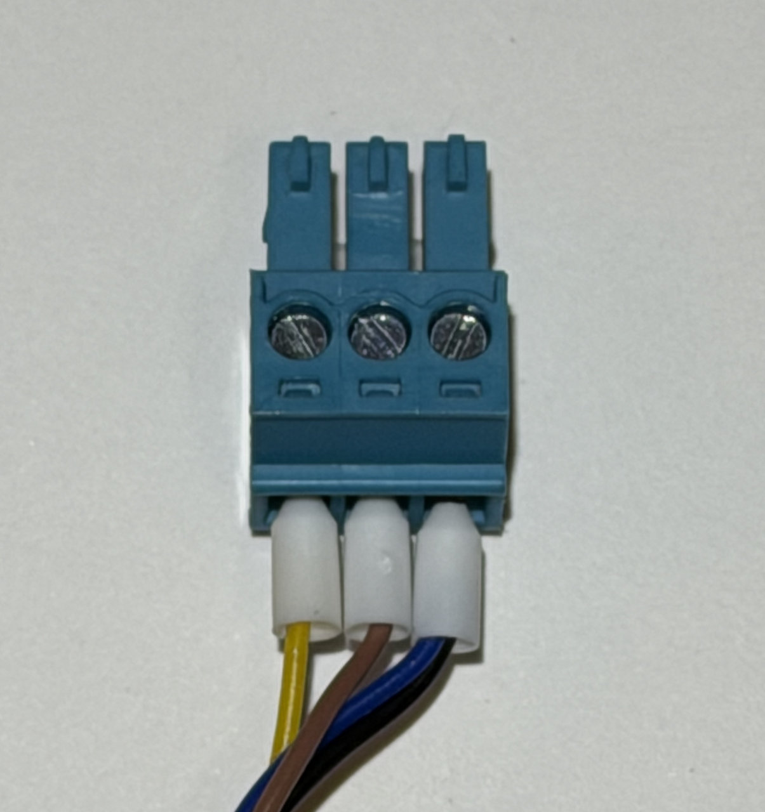
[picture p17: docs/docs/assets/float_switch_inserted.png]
Float switch wired up
- { data-title="Capacitive float switch wired up.  Yellow for output, brown for VCC, and blue for GND (black also tied to GND for this specific model).  If using a 2-wire mechanical float switch, connect the two wires to the Output and VCC terminals, omitting GND." }

</div>

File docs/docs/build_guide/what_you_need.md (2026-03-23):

# What You Need
This section covers everything you'll need to build the project: both parts and tools.  The parts list is prescriptive, the tools lists are mostly not.  For instance, "The tools you use for SMD assembly" will vary.

## Parts
### PCB
- [ ] All electronic components
- [ ] PCB + stencil

### Enclosure
- [ ] 28x M3x5x4 heat-set inserts (5mm diameter, 4mm depth)

### Final Assembly
- [ ] 28x M3x6mm screws
- [ ] 6x Peristaltic pumps
- [ ] 6x JST-XH pigtails (2-pin plug, 6" wire length)
- [ ] pH probe (BNC connector)
- [ ] ORP probe (BNC connector)
- [ ] 10k NTC thermistor (Beta value configurable)
- [ ] Conductivity probe (2-wire, K = 1.0)
- [ ] Float switch (mechanical or capacitive, required for solenoid operation)
- [ ] LCD screen (4.0" capacitive touch, model number MSP4031)
- [ ] Power supply (see Final Assembly section for specs)
- [ ] Heat-shrink tubing (optional)
- [ ] Flood sensor (optional)

<div class="grid cards" markdown>

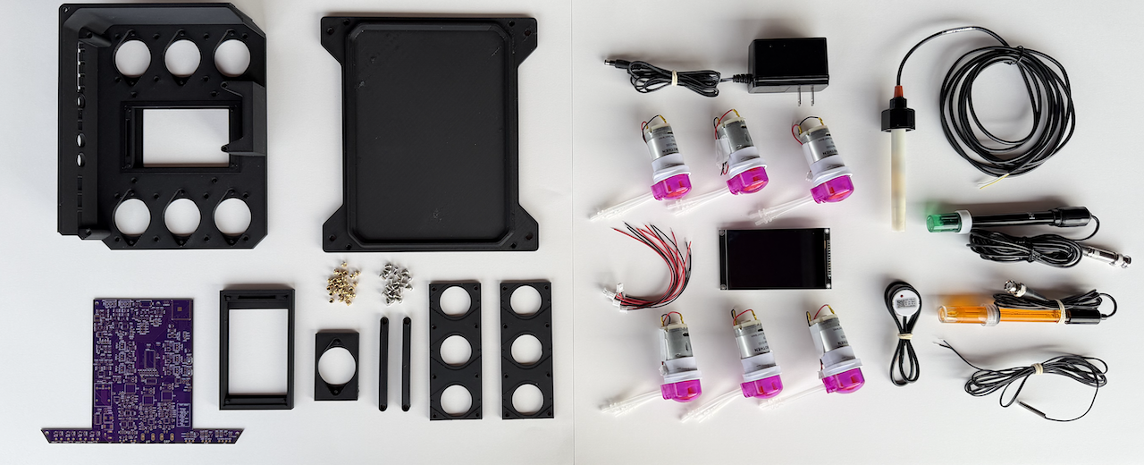
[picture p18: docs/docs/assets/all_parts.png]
All required parts
- { data-title="All parts required for assembly.  Left: PCB and all enclosure parts, including heat-set inserts and screws.  Right: Power supply, peristaltic pumps & connectors, screen, all sensors.  Not pictured: a big box of electronic components to populate the bare PCB." }

</div>

#### Selecting a Power Supply
There are a couple considerations you need to keep in mind when selecting a power supply:

- **Dimensions:** The barrel jack is 2.0mm ID, 5.5mm OD, center-positive.
- **Voltage:** Demetra is designed to operate using either a 12 or 24V DC power supplies.   This voltage gets routed directly to both the peristaltic dosing pumps and configurable outlets, so you should select your power supply voltage according to what pumps you're planning on using.  Worth noting, this does mean that you're locked into one voltage for both your pumps and outlets.
- **Current:** Without any load on the outlets, Demetra requires <1A of power.  Demetra's outlets can supply a maximum of 3A of current split between them.

## Tools
### PCB Assembly
- [ ] Surface-mount PCB soldering tools (see notes below for specific recommendations)
- [ ] Soldering iron, flux, solder, and solder wick for post-reflow touchups and installing through-hole components
- [ ] 99% isopropyl alcohol for flux cleanup (highly recommended to ensure sensor reliability)
- [ ] Multimeter (for testing)
- [ ] (Optional) Conformal Coating for the sensor section

**SMD soldering tools** - the below is what I use, not a prescriptive list:
  - Low-temperature solder paste (ChipQuik NC191LT10)
  - Solder paste squeegee (I use a metal drywall putty knife)
  - ESD-safe tweezers
  - Hakko 394 vacuum pick-up tool (not strictly needed, but I do quite like it)
  - Hakko omnivise (if you do much SMD soldering I can't recommend this highly enough)
  - Controleo3 reflow oven (this is a recent addition: early revisions were soldered using a toaster oven from Goodwill and a watchful eye)

I don't recommend this approach for the sake of your sanity, but all of the components on the board are large enough to be hand-soldered, if you have an insane amount of patience.  It'll take a _lot_ longer than solder paste and a reflow oven, but it is possible to do.

### Enclosure

- [ ] 3D printer (or pre-printed enclosure)
- [ ] Soldering iron to install heat-set inserts
- [ ] M3 heat-set insert soldering iron tip (optional, but highly recommended)

### Final Assembly

- [ ] Screwdriver that fits your M3x6mm screw heads (you'll also need a small flathead bit to tighten the screw terminals)
- [ ] Wire crimping tool + ferrules (optional, but makes for more reliable connections)

## Part Purchase Links 
These aren't affiliate links, they're just here to save you some time looking around for appropriate parts.

- Filament: [Amazon](https://www.amazon.com/eSUN-Filament-Printing-Dimensional-Accuracy/dp/B0D25JMYNS)
- Heat-set inserts: [Amazon (comes with soldering iron tip)](https://www.amazon.com/dp/B0D7M3LJDL)
- Screws: [Amazon](https://www.amazon.com/dp/B0CGTRWZ12)
- Screen: [Amazon](https://www.amazon.com/dp/B0CRGQN58D) [AliExpress](https://www.aliexpress.us/item/3256807422726669.html?) (Note: You need the TOUCH option on AliExpress)
- Peristaltic pumps: [AliExpress](https://www.aliexpress.us/item/3256804283799290.html)
- JST XH Pigtails for peristaltic pumps: [Amazon](https://www.amazon.com/dp/B073SNHTFK)

There are also some optional purchases that you might find useful:

- Wire crimping tool & ferrules: [Amazon](https://www.amazon.com/dp/B0DYJG235H?th=1)
- SMA to BNC adapter (if you have SMA pH or ORP sensors): [DigiKey](https://www.digikey.com/en/products/detail/rf-solutions/ADP-SMAF-BNCM/4271257)
- BNC to screw-terminal adapter (if your EC probe has a BNC connector and you don't want to chop it off -- understandable!) [Amazon](https://www.amazon.com/QMseller-Terminal-Connector-Coaxial-Adapter/dp/B07XY5XLFV/)

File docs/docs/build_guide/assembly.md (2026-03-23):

# Final Assembly
Now that you've printed the enclosure and assembled the PCB, you're ready to put everything together.

## Pre-Assembly
If you haven't flashed the firmware to the motherboard yet, it's recommended that you do so now.  This will let you confirm that the cable connection between the PCB and the screen is correct before proceeding with the rest of assembly.

## Assembly Steps

### 1. Install LCD Screen
- [ ] Connect the FFC cable to the LCD.  Ensure the cable is fully inserted and properly lined up prior to locking the connector.
- [ ] Position the 4.0" LCD screen in the front panel mounting hole, with the FFC connector pointing towards the top of the enclosure.
- [ ] Secure with 4 M3x6mm screws.
- [ ] Turn the enclosure around and confirm the screen is secured properly.  It should be sitting nicely in the enclosure and shouldn't have any give when pressed.

<div class="grid cards" markdown>

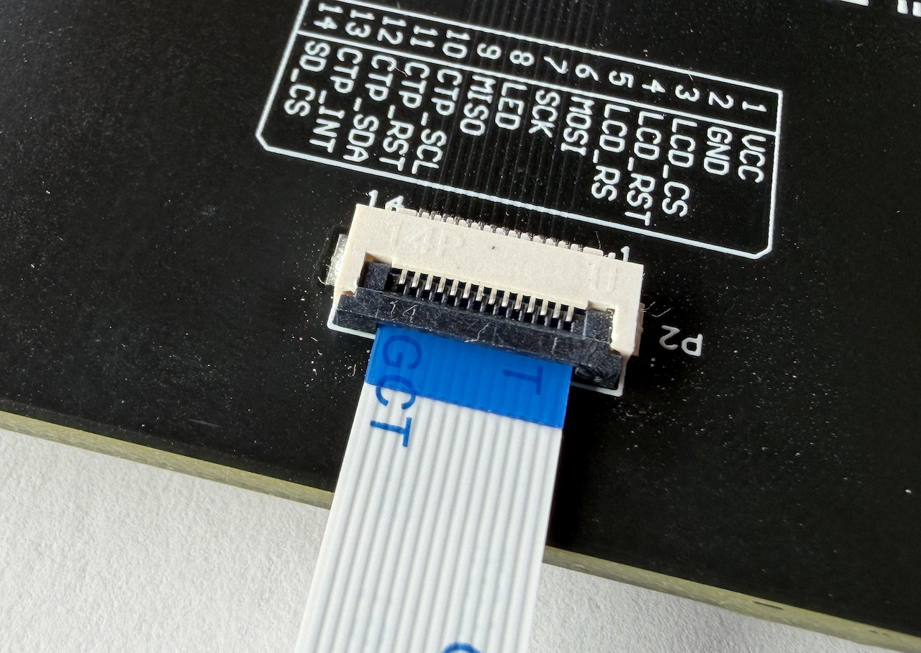
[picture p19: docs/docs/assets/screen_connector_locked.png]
Screen with FFC cable inserted
- 

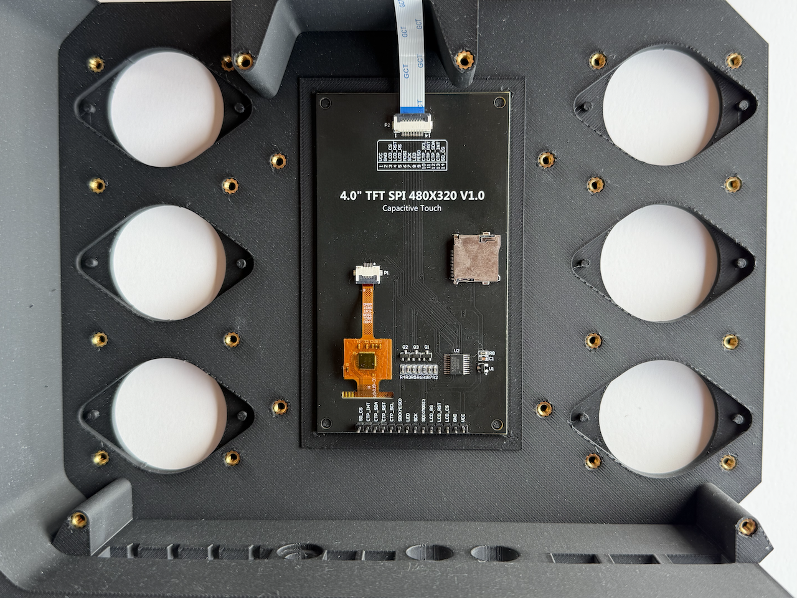
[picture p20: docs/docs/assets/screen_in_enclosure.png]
Screen properly aligned in enclosure
- 

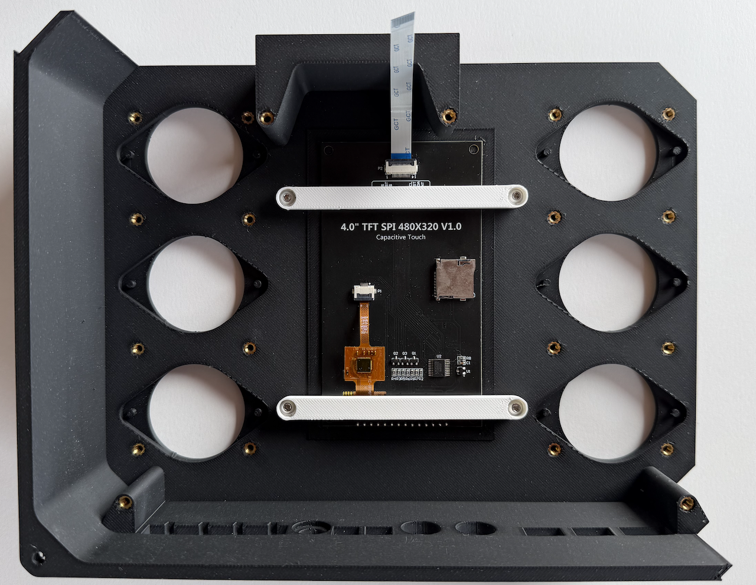
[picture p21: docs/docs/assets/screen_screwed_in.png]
Screen with retainers holding it in place
- 

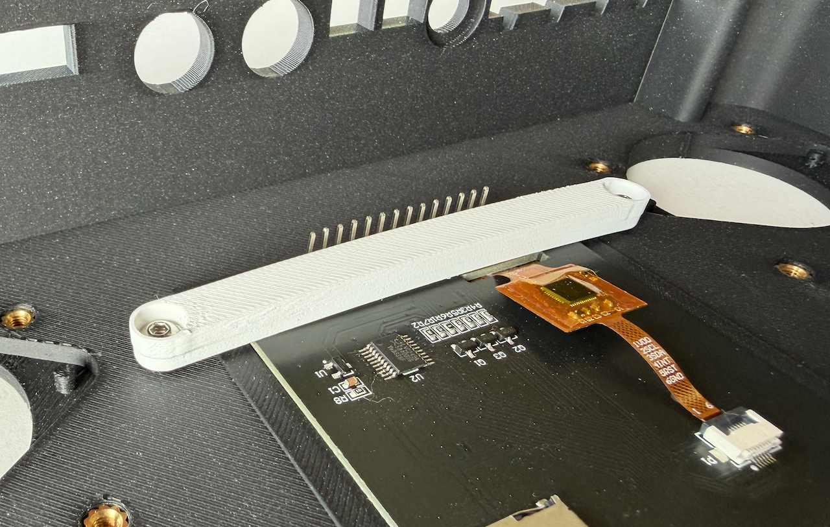
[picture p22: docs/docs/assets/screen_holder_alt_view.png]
Close-up of a retainer
-  

</div>

### 2. Install PCB
- [ ] Position the populated PCB in the enclosure, sliding the connectors into the bottom panel
- [ ] Connect the FFC cable from the LCD to the screen connector on the PCB
- [ ] Secure the PCB with 4 M3x6mm screws
- [ ] Now is an excellent time to turn the unit around and plug in the power supply.  Once the peristaltic pumps are installed, you can't remove the PCB without removing the pumps first.  If your screen cable is loose or misaligned, it's _way_ better to find that out now rather than after you've installed the pumps.

<div class="grid cards" markdown>

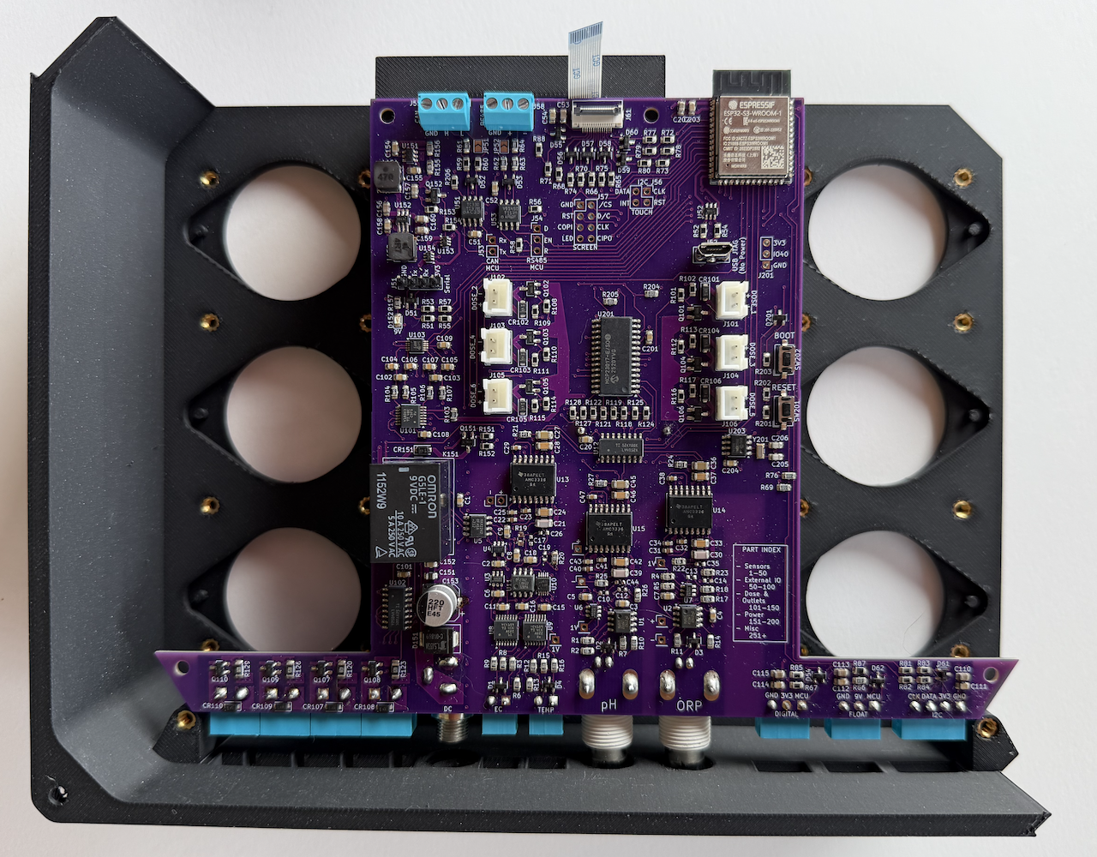
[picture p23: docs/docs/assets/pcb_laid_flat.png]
PCB in enclosure
- 

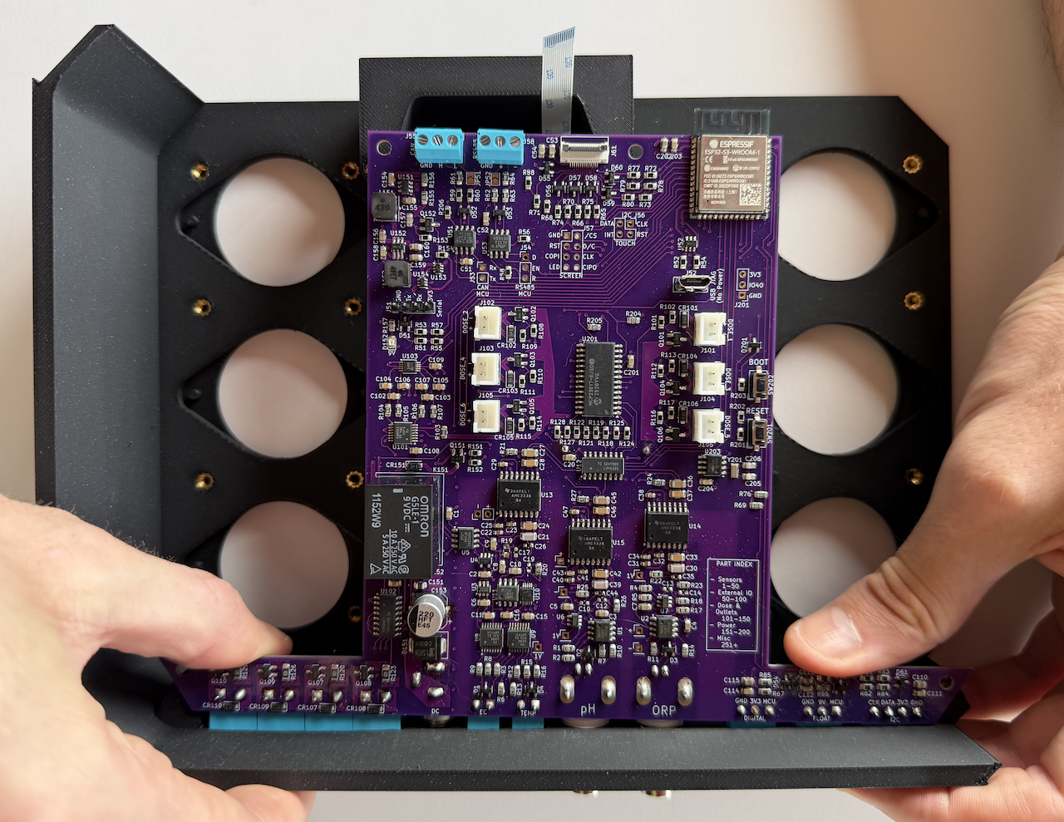
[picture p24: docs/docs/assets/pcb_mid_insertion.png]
PCB mid-insertion
-  

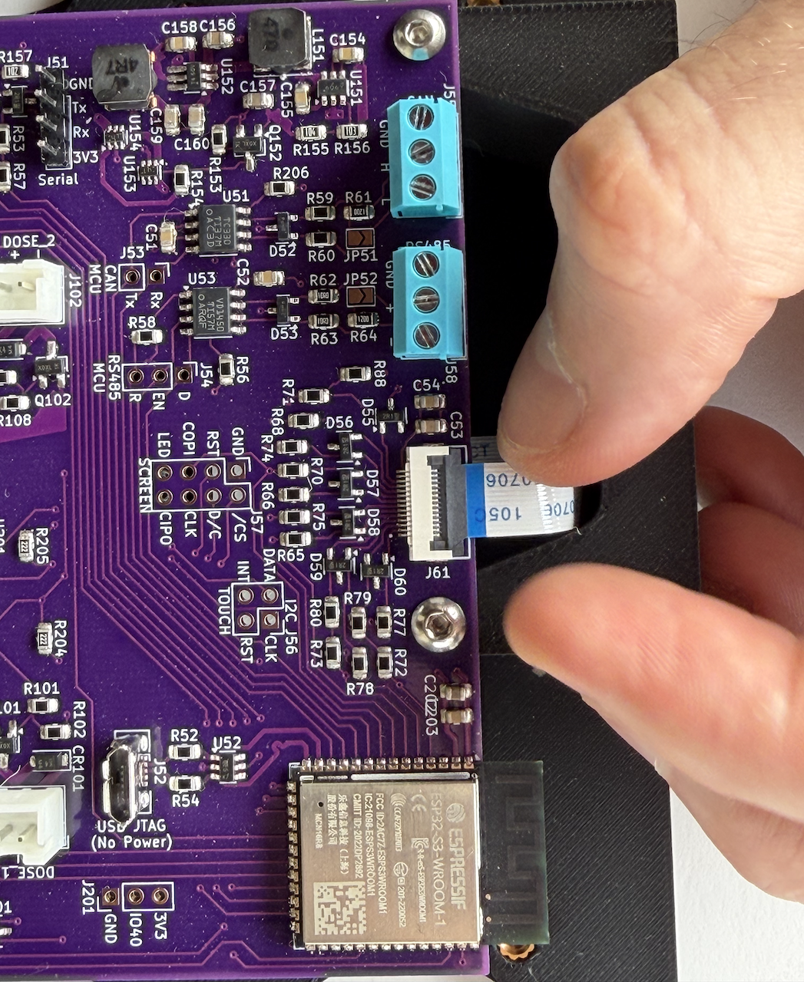
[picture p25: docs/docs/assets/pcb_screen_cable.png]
FFC inserted into the PCB's connector
- { data-title="The screen FFC inserted and locked into the PCB's connector.  Like with the screen, ensure the cable is fully inserted into the connector and properly aligned before locking the connector." }

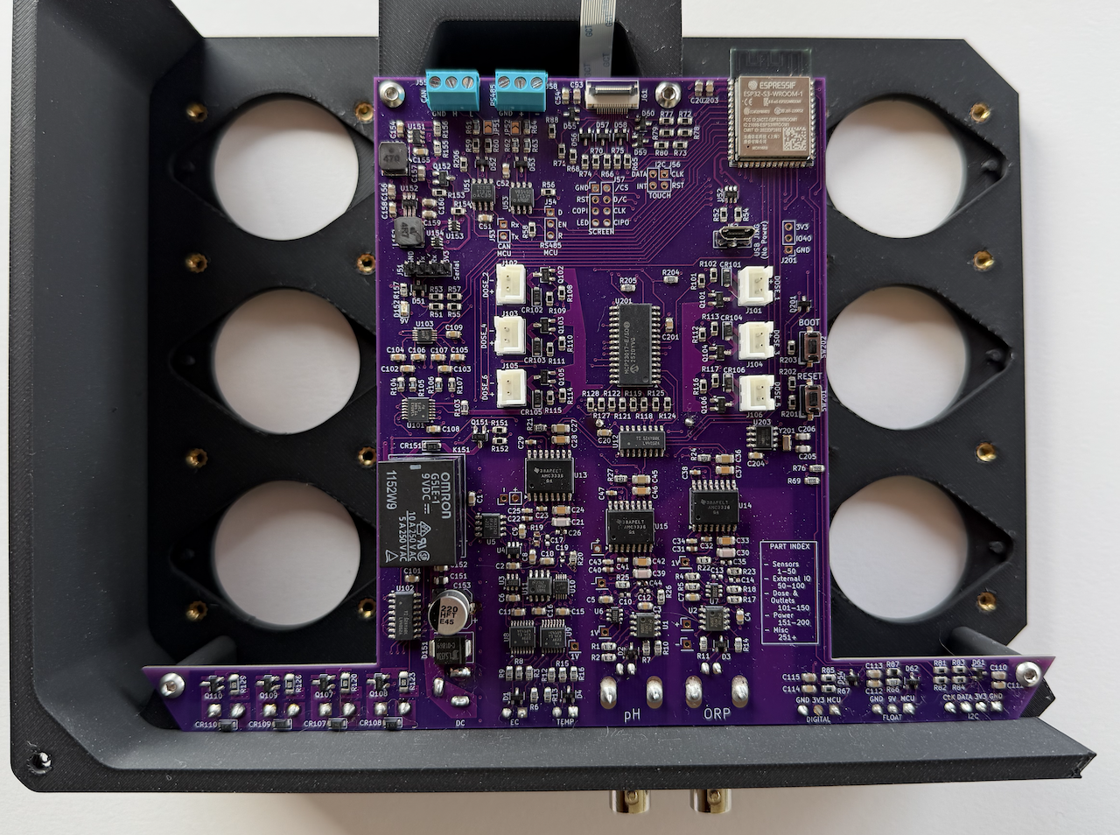
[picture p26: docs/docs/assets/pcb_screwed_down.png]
PCB Screwed In
- 

</div>

### 3. Install Peristaltic Pumps
- [ ] Remove the front housings from the pumps if you haven't already.
- [ ] Insert 3 pumps into the mounting holes on the enclosure , and feed the JST pigtails through the holes of one pump mounting plate.
- [ ] Push the pump mounting plate down, until it's slid over the all 3 pumps, and secure with 8 M3x6mm screws.
- [ ] Repeat for the other 3 pumps.
- [ ] Connect the JST pigtail connectors to the corresponding terminal blocks on the PCB -- they match positionally, so the bottom-left pump should connect to the bottom-left terminal block, etc.

<div class="grid cards" markdown>

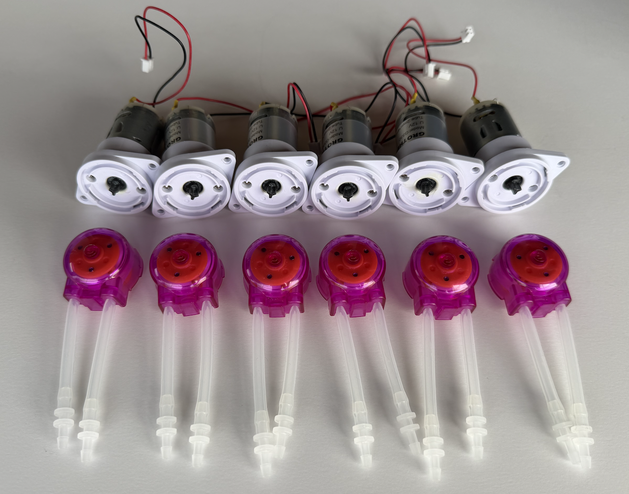
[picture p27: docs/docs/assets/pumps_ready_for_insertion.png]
Pumps ready for mounting
-  

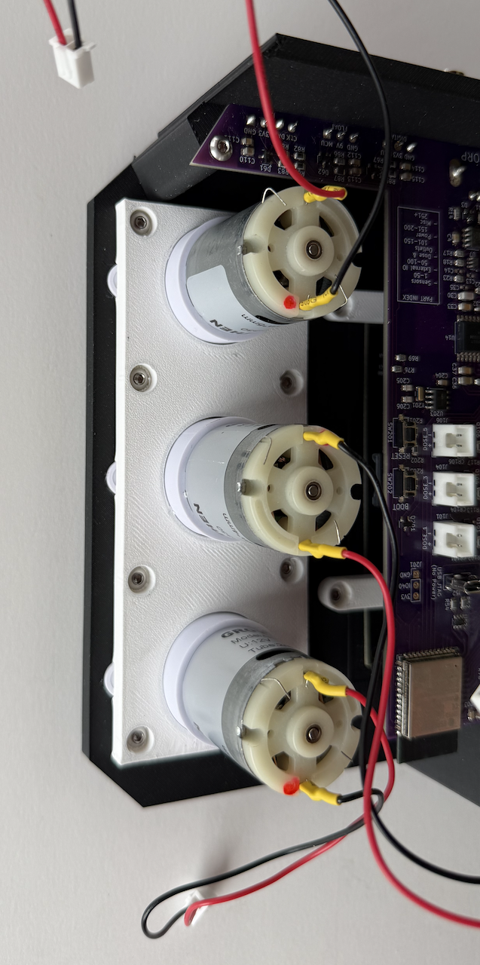
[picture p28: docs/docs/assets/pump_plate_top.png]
Pumps mounted securely
- 

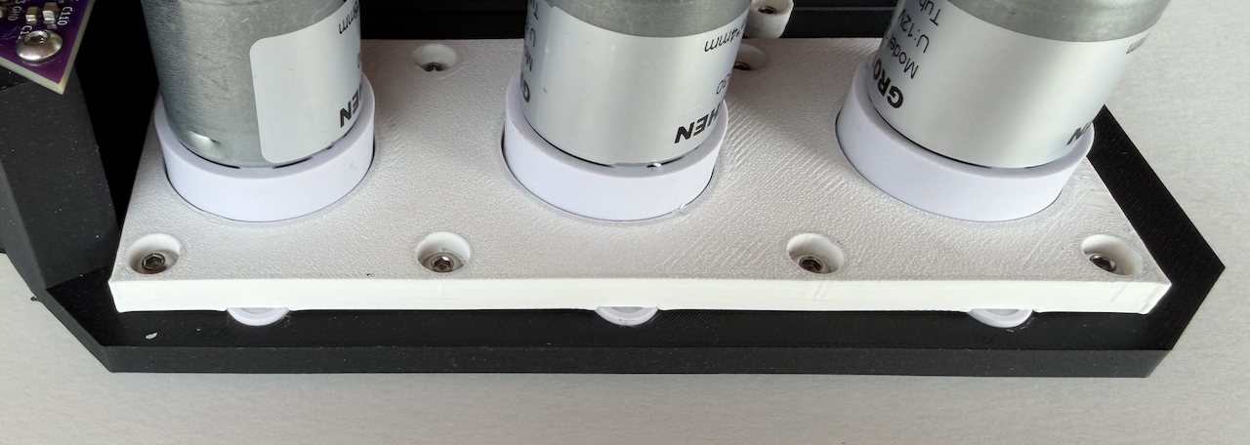
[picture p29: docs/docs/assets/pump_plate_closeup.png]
Close-up of mounted pumps
- { data-title="A close-up shot of a properly-mounted pump retaining plates.  The pumps will stick up above the enclosure wall about half a millimeter, and there will be a very small gap between the retaining plate and the inner wall of the enclosure." } 

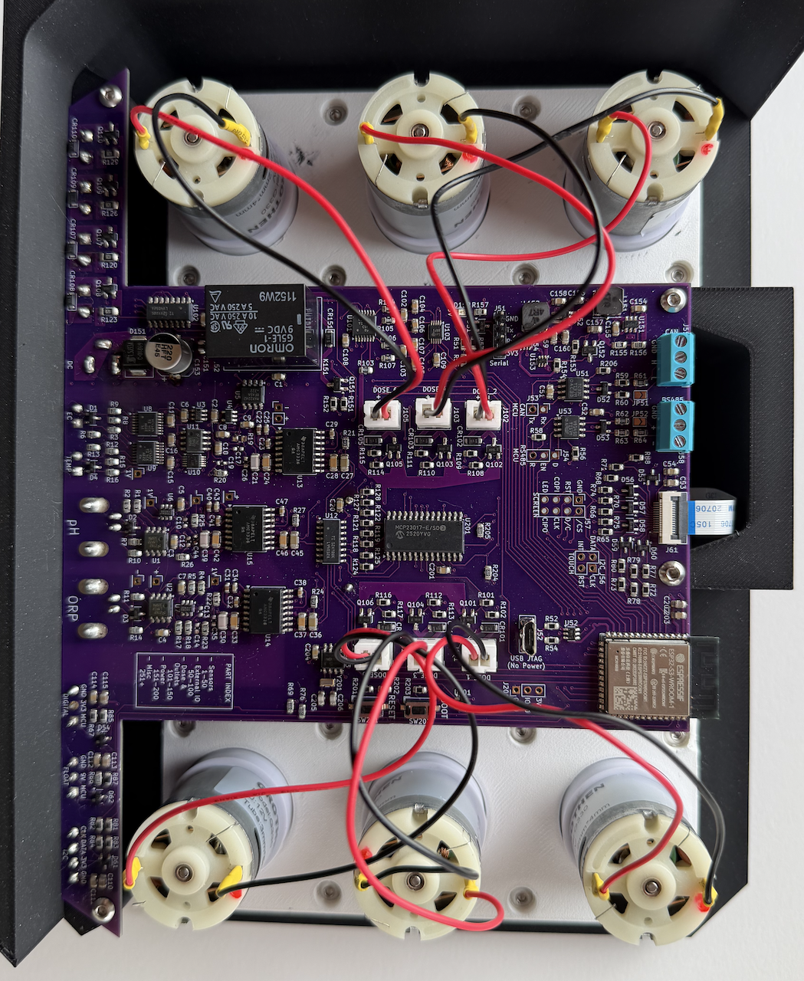
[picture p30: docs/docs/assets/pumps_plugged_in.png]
All pumps mounted
- 

</div>

### 4. Connect everything on the outside of the enclosure
- [ ] Turn the unit around and re-install the pump heads.  Going from top-to-bottom is slightly easier.
- [ ] Screw the included nuts onto the threads of the DC power jack and BNC jacks.

<div class="grid cards" markdown>

- Front of enclosure with pumps heads unattached

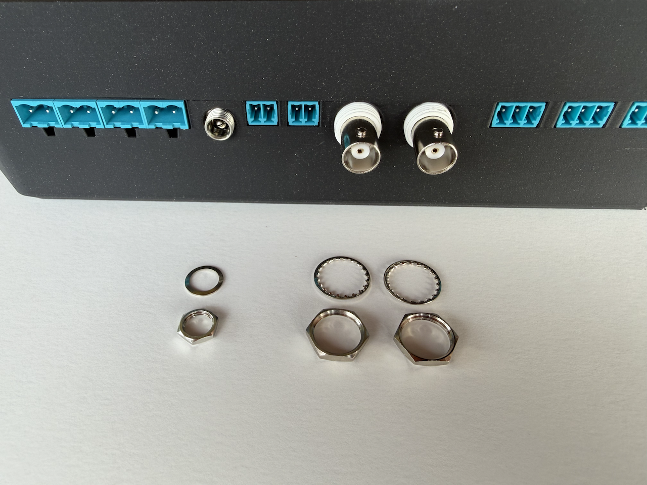
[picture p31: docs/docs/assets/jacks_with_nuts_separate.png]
Power and BNC washers and nuts
-  

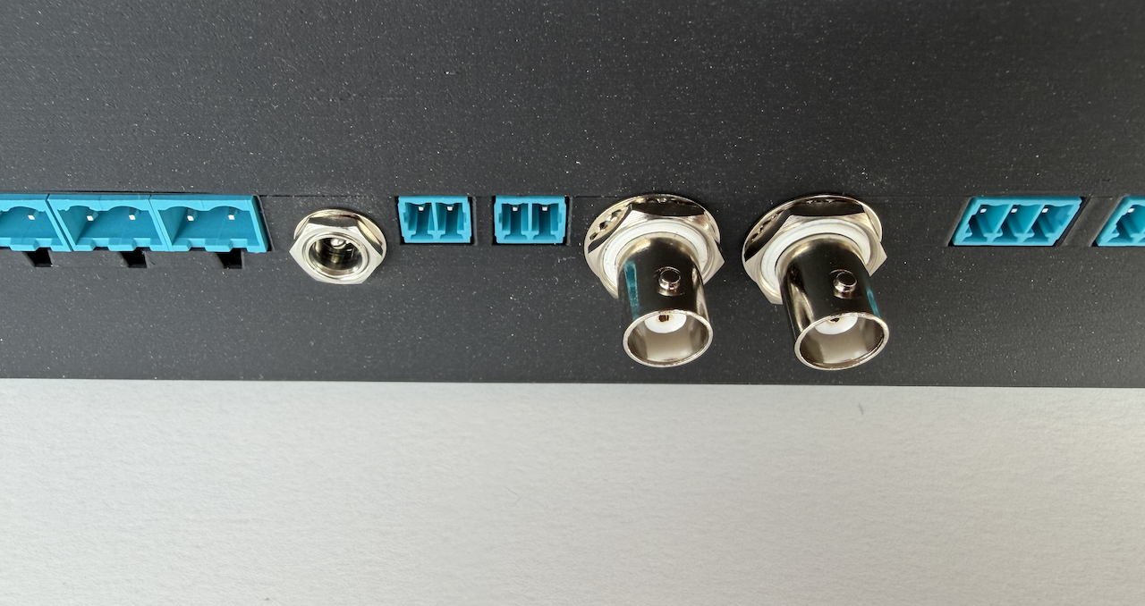
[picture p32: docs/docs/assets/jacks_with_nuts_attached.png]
Post-nut-installation
- 

- Everything secured 

</div>

### 5. Initial Power-On Check

- [ ] Power on the system
- [ ] Verify LCD displays status screen
- [ ] Check for any error indications

## Next Steps
Proceed to the [Setup](setup.md) section for initial configuration and setup steps.

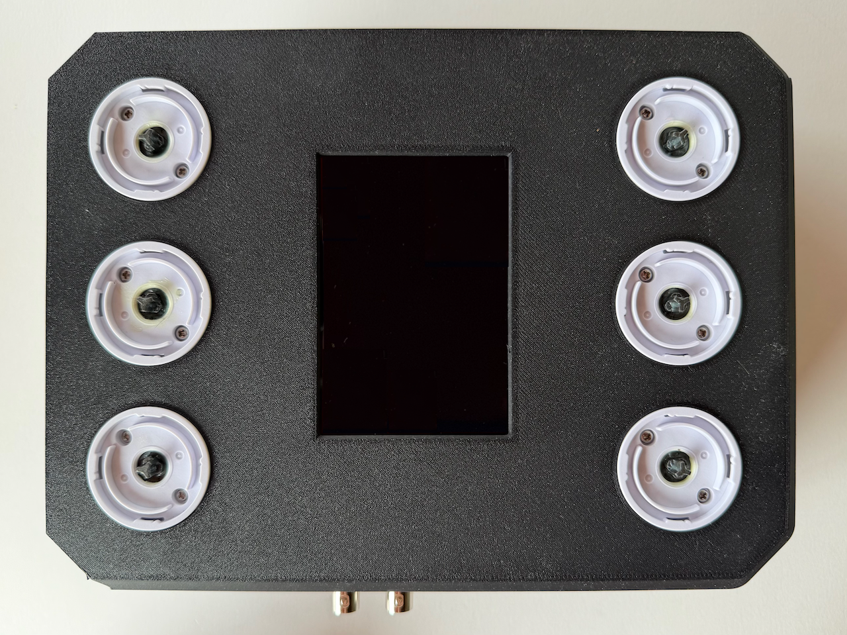
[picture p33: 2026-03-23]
docs/docs/assets/front_assembled.png

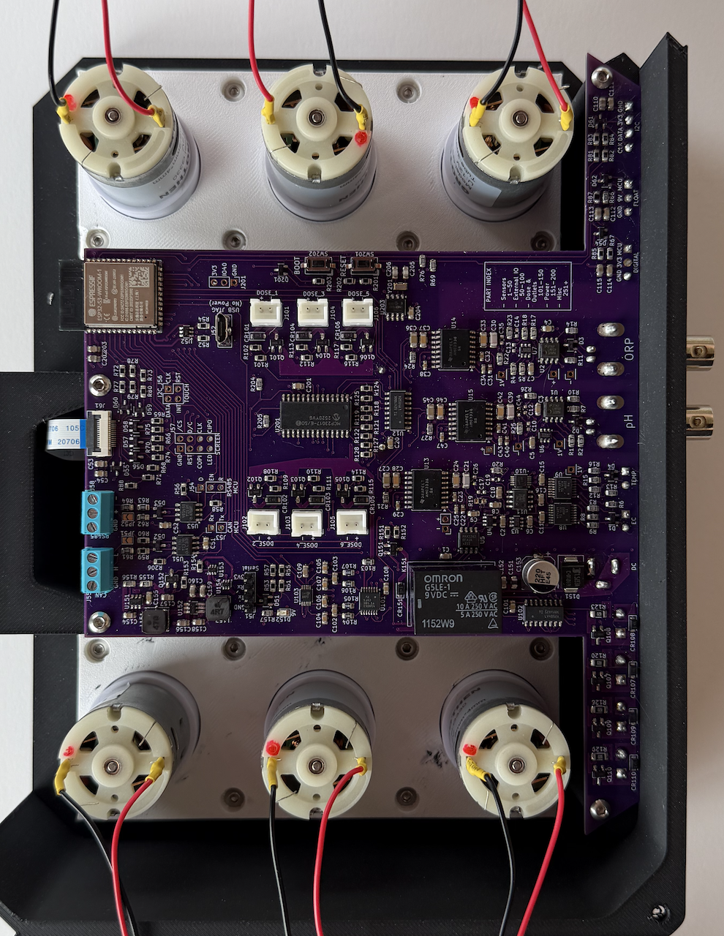
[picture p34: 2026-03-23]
docs/docs/assets/pumps_installed.png

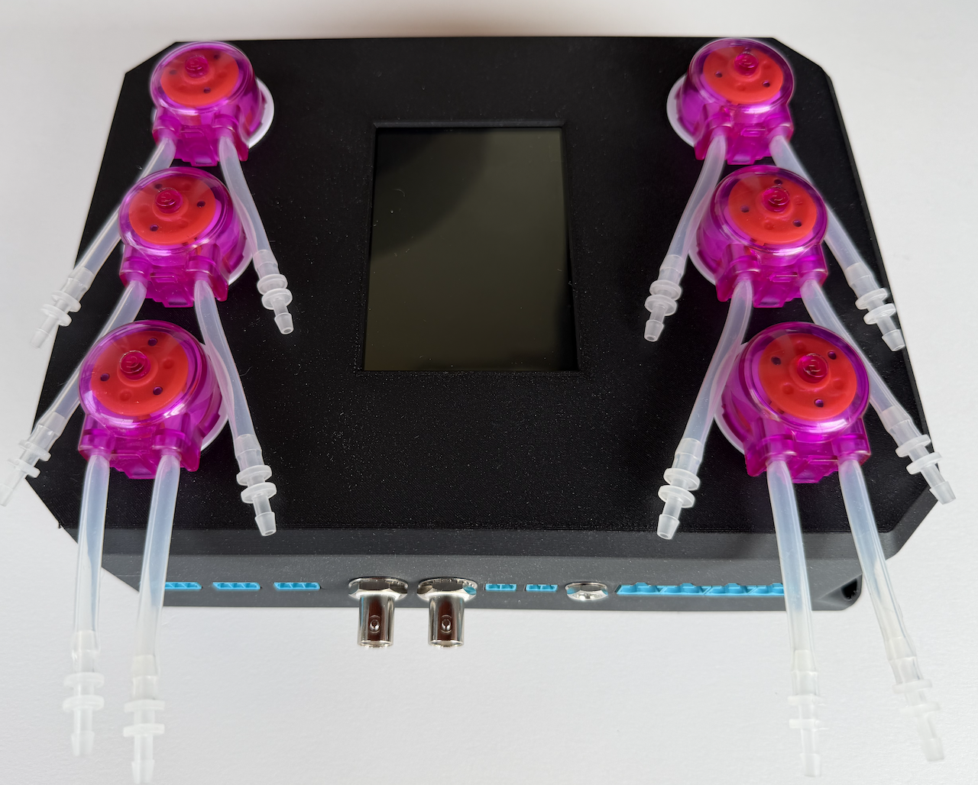
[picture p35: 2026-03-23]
docs/docs/assets/enclosure_all_assembled.png

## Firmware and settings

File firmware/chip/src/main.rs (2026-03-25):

#![deny(unsafe_code, dead_code)]
#![no_std]
#![no_main]
#![feature(type_alias_impl_trait)]
#![feature(asm_experimental_arch)]

extern crate alloc;

use core::cell::RefCell;

use lib::{
    config::device_config::DeviceConfig,
    peripherals::{rtc::Mcp7940, HardwarePumpController, SensorController},
    storage::{EmptyMetadata, RingBuffer},
    ui_backend::ui_runner::WINDOW_EVENT_CHANNEL,
    ui_types::MainWindow,
};

mod hardware_peripherals;
use hardware_peripherals::{
    EspTreatmentController, EspTreatmentControllerMutex, HardwareTouchInput, Sensors_1_0_0,
};

mod tasks;

mod esp_ui_backend;

use embassy_executor::Spawner;

use embassy_embedded_hal::shared_bus::blocking::i2c::I2cDevice;

use embassy_sync::{
    blocking_mutex::{raw::NoopRawMutex, Mutex as BlockingMutex},
    mutex::Mutex,
};
use embassy_time::Timer;
use esp_backtrace as _;
use esp_hal::{
    gpio::{Input, InputConfig, Level, Output, OutputConfig, Pull},
    i2c::master::{Config as I2cConfig, I2c},
    ledc::{
        channel::{self, ChannelIFace},
        timer::{self, TimerIFace},
        LSGlobalClkSource, Ledc, LowSpeed,
    },
    psram,
    rmt::{Rmt, RxChannelConfig, RxChannelCreator},
    time::Rate,
    timer::timg::TimerGroup,
    Blocking,
};
use esp_storage::FlashStorage;
use log::info;
use static_cell::StaticCell;

esp_bootloader_esp_idf::esp_app_desc!();

static ESP_PERIPHERALS_MUTEX: StaticCell<EspTreatmentControllerMutex> = StaticCell::new();

static LSTIMER0: StaticCell<esp_hal::ledc::timer::Timer<'static, LowSpeed>> = StaticCell::new();

static MCP23017: StaticCell<
    port_expander::dev::mcp23x17::Mcp23x17<
        RefCell<
            port_expander::dev::mcp23x17::Driver<
                port_expander::dev::mcp23x17::Mcp23017Bus<
                    hardware_peripherals::SharedI2cDevice<'static>,
                >,
            >,
        >,
    >,
> = StaticCell::new();

static MAIN_WINDOW: StaticCell<MainWindow> = StaticCell::new();

static SHARED_I2C_BUS: StaticCell<BlockingMutex<NoopRawMutex, RefCell<I2c<'static, Blocking>>>> =
    StaticCell::new();

static FLASH_STORAGE_INTERNALS: StaticCell<
    BlockingMutex<NoopRawMutex, hardware_peripherals::EspStorageInternals<'static>>,
> = StaticCell::new();

#[allow(dead_code, unsafe_code)]
fn print_stack_usage() {
    use core::arch::asm;
    let sp: u32;
    unsafe { asm!("mov {}, a1", out(reg) sp) };
    log::info!("Stack pointer: 0x{:08x}", sp);
}

#[esp_rtos::main()]
async fn main(spawner: Spawner) {
    esp_println::logger::init_logger(log::LevelFilter::Debug);

    info!("Booting...");

    let psram_config = psram::PsramConfig {
        ram_frequency: psram::SpiRamFreq::Freq80m,
        ..Default::default()
    };

    let peripherals = esp_hal::init(esp_hal::Config::default().with_psram(psram_config));
    esp_alloc::psram_allocator!(peripherals.PSRAM, esp_hal::psram);

    let timg0 = TimerGroup::new(peripherals.TIMG0);

    use esp_hal::interrupt::software::SoftwareInterruptControl;
    let software_interrupt = SoftwareInterruptControl::new(peripherals.SW_INTERRUPT);

    esp_rtos::start(timg0.timer0, software_interrupt.software_interrupt0);

    lib::state::init_clock(|| {
        esp_hal::time::Instant::now()
            .duration_since_epoch()
            .as_micros() as u64
    })
    .expect("Clock already initialized");

    let freq = Rate::from_mhz(80);

    info!("Initialized");

    ///////////////  Break out hardware pins  ///////////////
    //
    // Pin definitions -- we don't do anything with the pins here.
    // This is just to have a centralized spot where all of the pin mappings
    // live, in case things get moved around on the board between iterations.
    // It's also nice to be passing around named pins rather than just numbers.

    let i2c_data_pin = peripherals.GPIO4;
    let i2c_clk_pin = peripherals.GPIO5;

    let spi_0_sck_pin = peripherals.GPIO7;
    let spi_0_copi_pin = peripherals.GPIO15;
    let spi_0_cipo_pin = peripherals.GPIO6;

    let relay_pin = Output::new(peripherals.GPIO9, Level::High, OutputConfig::default());

    let screen_cs_pin = peripherals.GPIO21;
    let screen_reset_pin = peripherals.GPIO48;
    let screen_dc_pin = peripherals.GPIO47;

    let touch_interrupt_pin = peripherals.GPIO41;
    let touch_reset_pin = peripherals.GPIO42;

    let temp_ec_sel_pin = peripherals.GPIO46;
    let temp_ec_sqw_pin = peripherals.GPIO3;

    let float_sensor_pin = peripherals.GPIO1;

    let adc_clock_pin = peripherals.GPIO14;
    let adc_data_pin = peripherals.GPIO13;
    let adc_diag_pin = peripherals.GPIO12;

    // Currently no software support for these interfaces, but it's nice
    // to have the pin definitions already built in for future reference.
    let _rs435_d_data_pin = peripherals.GPIO16;
    let _rs435_r_data_pin = peripherals.GPIO17;
    let _rs435_drive_pin = peripherals.GPIO10;
    let _can_rx_pin = peripherals.GPIO18;
    let _can_tx_pin = peripherals.GPIO8;
    let _can_stb_pin = peripherals.GPIO45;
    let _external_i2c_sda_pin = peripherals.GPIO38;
    let _external_i2c_scl_pin = peripherals.GPIO39;
    let _free_pin = peripherals.GPIO40;
    let _external_digital_pin = peripherals.GPIO2;

    ///////////////  Instantiate I2C  ///////////////

    let shared_i2c_peripheral = I2c::new(
        peripherals.I2C0,
        I2cConfig::default().with_frequency(Rate::from_khz(400)),
    )
    .unwrap()
    .with_sda(i2c_data_pin)
    .with_scl(i2c_clk_pin);

    let shared_i2c_bus =
        &*SHARED_I2C_BUS.init(BlockingMutex::new(RefCell::new(shared_i2c_peripheral)));

    ///////////////  Instantiate MCP23017  ///////////////

    let mcp_i2c = I2cDevice::new(shared_i2c_bus);
    let mcp23017 = MCP23017.init(port_expander::Mcp23x17::new_mcp23017(
        mcp_i2c, false, false, false,
    ));
    let mcp_pins = mcp23017.split();

    let mcp_dose_0_pin = mcp_pins.gpb7.into_output().unwrap();
    let mcp_dose_1_pin = mcp_pins.gpa0.into_output().unwrap();
    let mcp_dose_2_pin = mcp_pins.gpb6.into_output().unwrap();
    let mcp_dose_3_pin = mcp_pins.gpa1.into_output().unwrap();
    let mcp_dose_4_pin = mcp_pins.gpb5.into_output().unwrap();
    let mcp_dose_5_pin = mcp_pins.gpa2.into_output().unwrap();
    let mcp_outlet_0_pin = mcp_pins.gpa6.into_output().unwrap();
    let mcp_outlet_1_pin = mcp_pins.gpa5.into_output().unwrap();
    let mcp_outlet_2_pin = mcp_pins.gpb0.into_output().unwrap();
    let mcp_outlet_3_pin = mcp_pins.gpa7.into_output().unwrap();
    let mcp_adc_sel_0_pin = mcp_pins.gpb1.into_output().unwrap();
    let mcp_adc_sel_1_pin = mcp_pins.gpb2.into_output().unwrap();

    let mut mcp_screen_led_pin = mcp_pins.gpb4.into_output().unwrap();

    let mcp_current_sense_mux_a_pin = mcp_pins.gpa3.into_output().unwrap();
    let mcp_current_sense_mux_b_pin = mcp_pins.gpa4.into_output().unwrap();

    mcp_screen_led_pin.set_high().unwrap();

    ///////////// Instantiate RTC //////////////

    let mut rtc = Mcp7940::new(I2cDevice::new(shared_i2c_bus)).unwrap();
    info!("RTC instantiated");

    match rtc.get_datetime() {
        Ok(boot_time) => {
            let boot_micros = esp_hal::time::Instant::now()
                .duration_since_epoch()
                .as_micros();
            let time_info =
                lib::peripherals::rtc::SystemTimeInfo::new(boot_time, boot_micros as i64);
            lib::state::set_system_time_info(time_info).await;
            info!("System time initialized from RTC: {}", boot_time);
        }
        Err(e) => {
            log::error!("Failed to read RTC on boot: {}", e);
        }
    }

    ///////////// Spawn UI on CPU1 //////////////

    // Slint needs more stack space to set up than we can provide on the actual stack.
    // So the solution is to just leak
    #[allow(unsafe_code)]
    let second_core_stack: &'static mut esp_hal::system::Stack<524288> = {
        let b = unsafe {
            alloc::boxed::Box::<esp_hal::system::Stack<524288>>::new_zeroed().assume_init()
        };
        alloc::boxed::Box::leak(b)
    };

    use esp_rtos::embassy::Executor;

    esp_rtos::start_second_core(
        peripherals.CPU_CTRL,
        software_interrupt.software_interrupt1,
        second_core_stack,
        move || {
            static EXECUTOR: StaticCell<Executor> = StaticCell::new();
            let executor = EXECUTOR.init(Executor::new());

            executor.run(|spawner| {
                spawner
                    .spawn(crate::tasks::render_ui(
                        WINDOW_EVENT_CHANNEL.receiver(),
                        peripherals.SPI2,
                        Output::new(spi_0_sck_pin, Level::Low, OutputConfig::default()),
                        Output::new(spi_0_copi_pin, Level::Low, OutputConfig::default()),
                        Input::new(spi_0_cipo_pin, InputConfig::default()),
                        Output::new(screen_cs_pin, Level::High, OutputConfig::default()),
                        Output::new(screen_dc_pin, Level::Low, OutputConfig::default()),
                        Output::new(screen_reset_pin, Level::High, OutputConfig::default()),
                        peripherals.DMA_CH0,
                        TimerGroup::new(peripherals.TIMG1),
                    ))
                    .ok();
            });
        },
    );

    ///////////////  Instantiate Flash and Ring Buffers  ///////////////

    // esp_rtos::start_second_core takes our CPU_CTRL as input, but only needs it in the
    // context of core startup.  By the time this function steals the CPU_CTRL, start_second_core
    // is finished with it, so stealing it here doesn't cause problems.
    #[allow(unsafe_code)]
    let stolen_cpu_control =
        unsafe { esp_hal::system::CpuControl::new(esp_hal::peripherals::CPU_CTRL::steal()) };

    let flash_storage_internals = FLASH_STORAGE_INTERNALS.init(BlockingMutex::new(
        hardware_peripherals::EspStorageInternals::new(
            FlashStorage::new(peripherals.FLASH),
            stolen_cpu_control,
        ),
    ));

    let mut config_ring_buffer = RingBuffer::<
        DeviceConfig,
        EmptyMetadata,
        hardware_peripherals::EspStorage,
        esp_storage::FlashStorageError,
    >::new(
        lib::storage::CONFIGS_START_ADDRESS,
        lib::storage::CONFIGS_END_ADDRESS,
        hardware_peripherals::EspStorage::new(flash_storage_internals),
    )
    .expect("config partition addresses must be page-aligned");
    info!("Ring buffer instantiated");

    let log_ring_buffer = lib::logging::LogRingBuffer::<
        hardware_peripherals::EspStorage,
        esp_storage::FlashStorageError,
    >::new(
        lib::storage::LOGS_START_ADDRESS,
        lib::storage::LOGS_END_ADDRESS,
        hardware_peripherals::EspStorage::new(flash_storage_internals),
    )
    .expect("log partition addresses must be page-aligned");
    let log_logger = lib::logging::RingBufferLogger::new(log_ring_buffer);
    info!("Log ring buffer instantiated");

    match config_ring_buffer.read_latest_record() {
        Ok(None) => {}
        Ok(Some((config, _))) => {
            log::info!("Read config from flash storage: {:?}", config);
            lib::storage::set_device_config(config).await;
        }
        Err(_) => {
            panic!("Failed to read latest config from flash storage")
        }
    };

    ///////////////  Instantiate EspTreatmentController  ///////////////

    let mut ledc = Ledc::new(peripherals.LEDC);
    ledc.set_global_slow_clock(LSGlobalClkSource::APBClk);

    let mut lstimer0 = ledc.timer::<LowSpeed>(timer::Number::Timer0);
    lstimer0
        .configure(timer::config::Config {
            duty: timer::config::Duty::Duty2Bit,
            clock_source: timer::LSClockSource::APBClk,
            frequency: Rate::from_hz(80_000_000 / 8),
        })
        .unwrap();

    let lstimer0_static = LSTIMER0.init(lstimer0);

    let mut adc_ledc_channel = ledc.channel::<LowSpeed>(channel::Number::Channel0, adc_clock_pin);
    adc_ledc_channel
        .configure(channel::config::Config {
            timer: lstimer0_static,
            duty_pct: 50,
            drive_mode: esp_hal::gpio::DriveMode::PushPull,
        })
        .unwrap();

    let rmt = Rmt::new(peripherals.RMT, freq).unwrap().into_async();

    let rmt_channel = rmt
        .channel4
        .configure_rx(
            adc_data_pin,
            RxChannelConfig::default()
                .with_clk_divider(1)
                .with_carrier_modulation(false)
                .with_filter_threshold(0)
                // During normal functionality, the AMC3336 can only emit
                // a max of 127 pulses of the same value in a row.
                .with_idle_threshold(130),
        )
        .unwrap();

    let sensors_raw = Sensors_1_0_0::init(
        rmt_channel,
        mcp_adc_sel_0_pin,
        mcp_adc_sel_1_pin,
        adc_ledc_channel,
        Output::new(temp_ec_sel_pin, Level::Low, OutputConfig::default()),
        Output::new(temp_ec_sqw_pin, Level::Low, OutputConfig::default()),
        Input::new(adc_diag_pin, InputConfig::default().with_pull(Pull::Up)),
    );
    info!("Sensors initialized");

    let current_sense_adc_i2c = I2cDevice::new(shared_i2c_bus);

    let pump_controller = HardwarePumpController::new(
        [
            mcp_dose_0_pin,
            mcp_dose_1_pin,
            mcp_dose_2_pin,
            mcp_dose_3_pin,
            mcp_dose_4_pin,
            mcp_dose_5_pin,
        ],
        [
            mcp_outlet_0_pin,
            mcp_outlet_1_pin,
            mcp_outlet_2_pin,
            mcp_outlet_3_pin,
        ],
        current_sense_adc_i2c,
        mcp_current_sense_mux_a_pin,
        mcp_current_sense_mux_b_pin,
        relay_pin,
    )
    .await
    .unwrap();
    info!("Pump controller initialized");

    let sensor_controller = SensorController::new(sensors_raw);
    info!("Sensor controller initialized");

    let tc = EspTreatmentController::initialize(pump_controller, sensor_controller);
    info!("EspTreatmentController initialized");

    let esp_peripherals_mutex = ESP_PERIPHERALS_MUTEX.init(Mutex::new(tc));
    info!("Peripherals instantiated");

    ///////////////  Spawn Tasks  ///////////////

    let hardware_touch_i2c = I2cDevice::new(shared_i2c_bus);

    spawner.spawn(tasks::log_drain(log_logger)).unwrap();
    spawner
        .spawn(tasks::read_touch_input(
            hardware_touch_i2c,
            Input::new(
                touch_interrupt_pin,
                InputConfig::default().with_pull(Pull::Up),
            ),
            WINDOW_EVENT_CHANNEL.sender(),
            Output::new(touch_reset_pin, Level::Low, OutputConfig::default()),
        ))
        .unwrap();
    spawner
        .spawn(tasks::process_ui_update_messages(
            lib::ui_backend::actions::UI_ACTION_CHANNEL.receiver(),
            rtc,
            esp_peripherals_mutex,
            config_ring_buffer,
        ))
        .unwrap();
    spawner
        .spawn(tasks::outlet_scheduler(esp_peripherals_mutex))
        .unwrap();
    spawner
        .spawn(tasks::read_and_dose(esp_peripherals_mutex))
        .unwrap();
    spawner
        .spawn(tasks::monitor_pump_current(esp_peripherals_mutex))
        .unwrap();
    spawner
        .spawn(tasks::fill_reservoir(
            Input::new(float_sensor_pin, InputConfig::default().with_pull(Pull::Up)),
            esp_peripherals_mutex,
        ))
        .unwrap();

    loop {
        let _stats: esp_alloc::HeapStats = esp_alloc::HEAP.stats();
        Timer::after_secs(10).await;
        log::info!("Heap stats: {:?}", _stats);
    }
}

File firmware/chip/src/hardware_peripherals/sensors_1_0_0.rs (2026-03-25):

use core::{
    future::Future,
    iter::Iterator,
    pin::pin,
    task::{Context, Poll, Waker},
};

use embassy_time::{Duration, Instant, Timer};

use esp_hal::{
    gpio::{Input, Output},
    ledc::{
        channel::{Channel as LedcChannel, ChannelIFace, Error as LedcChannelError},
        LowSpeed,
    },
    rmt::{Channel, Error as RmtError, PulseCode, Rx},
    Async,
};

use log::debug;

type MuxPinError = port_expander::PinError<
    embassy_embedded_hal::shared_bus::I2cDeviceError<esp_hal::i2c::master::Error>,
>;

#[derive(Debug)]
#[allow(dead_code)]
enum SensorReadError {
    IsolatedPowerProblem,
    ClockStartFailure(LedcChannelError),
    MuxSelect(MuxPinError),
    Rmt(RmtError),
    InsufficientData,
}

use lib::{
    peripherals::{cic_filter_order_3, OversampleRatio, SensorError, SensorReadRaw},
    ui_types::SensorType,
};

use super::type_aliases::McpOutputPin;

const OSR: OversampleRatio = OversampleRatio::_1024;
const OSR_DIVISOR: u32 = OSR.get_cnc_filter_cap();
const SINC_FILTER_ORDER: usize = 3;
const RMT_BUFFER_LEN: usize = OSR as usize * (SINC_FILTER_ORDER + 1) / 2 + 1;

const VOLTAGE_REFERENCE_MV: f32 = 1024.0;
const ADC_RANGE: f32 = 2.5;

pub struct RmtReadings<'a> {
    items: &'a [PulseCode; RMT_BUFFER_LEN],
}

impl<'a> RmtReadings<'a> {
    fn new(items: &'a [PulseCode; RMT_BUFFER_LEN]) -> Self {
        Self { items }
    }
}

impl<'a> IntoIterator for &'a RmtReadings<'a> {
    type Item = bool;
    type IntoIter = RmtBitIterator<'a>;

    fn into_iter(self) -> RmtBitIterator<'a> {
        RmtBitIterator::new(&self.items)
    }
}

pub struct RmtBitIterator<'a> {
    items: &'a [PulseCode],
    pulse_code_value: bool,
    pulse_code_quantity: u16,
    bit_idx: usize,
    first_pulse_in_code: bool,
}

impl<'a> RmtBitIterator<'a> {
    fn new(items: &'a [PulseCode; RMT_BUFFER_LEN]) -> Self {
        // log::info!("RMT ITEMS: {:?}", items);
        Self {
            items,
            pulse_code_value: false,
            pulse_code_quantity: 0,
            bit_idx: 0,
            first_pulse_in_code: true,
        }
    }

    fn read_next_pulse_set(&mut self) {
        match self.first_pulse_in_code {
            true => {
                self.pulse_code_value = self.items[self.bit_idx].level1().into();
                self.pulse_code_quantity = self.items[self.bit_idx].length1();
                if self.pulse_code_quantity % 4 != 0 {
                    log::warn!(
                        "Pulse code quantity is not a multiple of 4: {}",
                        self.pulse_code_quantity
                    );
                }
                self.pulse_code_quantity /= 4;
                self.first_pulse_in_code = false;
            }
            false => {
                self.pulse_code_value = self.items[self.bit_idx].level2().into();
                self.pulse_code_quantity = self.items[self.bit_idx].length2();
                self.first_pulse_in_code = true;
                if self.pulse_code_quantity % 4 != 0 {
                    log::warn!(
                        "Pulse code quantity is not a multiple of 4: {}",
                        self.pulse_code_quantity
                    );
                }
                self.pulse_code_quantity /= 4;
                self.bit_idx += 1;
            }
        }
    }
}

impl<'a> Iterator for RmtBitIterator<'a> {
    type Item = bool;

    fn next(&mut self) -> Option<Self::Item> {
        // Indicates we've sent out all the pulses from the most-recent block
        if self.pulse_code_quantity == 0 {
            // Indicates we're through the buffer, so nothing to follow up with
            if self.bit_idx >= RMT_BUFFER_LEN {
                return None;
            }
            self.read_next_pulse_set();
            // If this is 0 or >= 128 after `read_next_pulse_set` it means
            // the receiver went idle and stopped receiving data.
            // AMC3336 cannot emit pulses >= 128 in a non-error state.
            if self.pulse_code_quantity == 0 || self.pulse_code_quantity >= 128 {
                return None;
            }
        }
        self.pulse_code_quantity -= 1;
        return Some(self.pulse_code_value);
    }
}

#[derive(Clone, Copy, Debug)]
enum SensorStatus {
    On,
    Off,
}

#[allow(non_camel_case_types)]
pub struct Sensors_1_0_0<'a> {
    rmt_channel: Channel<'a, Async, Rx>,
    diag_pin: Input<'a>,
    adc_mux_sel_a: McpOutputPin<'a>,
    adc_mux_sel_b: McpOutputPin<'a>,
    readings: [PulseCode; RMT_BUFFER_LEN],
    adc_clock: LedcChannel<'a, LowSpeed>,
    temp_ec_sel: Output<'a>,
    temp_ec_sqw: Output<'a>,
    sensor_status: SensorStatus,
}

impl<'a> Sensors_1_0_0<'a> {
    pub fn init(
        rmt_channel: Channel<'a, Async, Rx>,
        adc_mux_sel_a: McpOutputPin<'a>,
        adc_mux_sel_b: McpOutputPin<'a>,
        adc_clock: LedcChannel<'a, LowSpeed>,
        temp_ec_sel: Output<'a>,
        temp_ec_sqw: Output<'a>,
        diag_pin: Input<'a>,
    ) -> Self {
        Self {
            rmt_channel,
            diag_pin,
            adc_mux_sel_a,
            adc_mux_sel_b,
            readings: [PulseCode::default(); RMT_BUFFER_LEN],
            adc_clock,
            temp_ec_sel,
            temp_ec_sqw,
            sensor_status: SensorStatus::Off,
        }
    }

    async fn turn_clock_on(&mut self) -> Result<(), SensorReadError> {
        match self.sensor_status {
            SensorStatus::On => Ok(()),
            SensorStatus::Off => {
                self.adc_clock
                    .set_duty(50)
                    .map_err(SensorReadError::ClockStartFailure)?;
                self.sensor_status = SensorStatus::On;
                Timer::after_millis(250).await;
                Ok(())
            }
        }
    }

    async fn turn_clock_off(&mut self) -> Result<(), SensorReadError> {
        match self.sensor_status {
            SensorStatus::On => {
                self.adc_clock
                    .set_duty(0)
                    .map_err(SensorReadError::ClockStartFailure)?;
                self.sensor_status = SensorStatus::Off;
            }
            SensorStatus::Off => (),
        }
        Ok(())
    }
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

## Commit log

2026-03-25 Add cargo fmt --check to pre-commit hook (#4)
    * Add cargo fmt --check to pre-commit hook and format codebase
    Run cargo fmt across the entire firmware workspace to fix existing
    formatting issues, and add cargo fmt --check as the first step in
    the pre-commit hook so formatting is enforced going forward.
    * Fix redundant_closure clippy errors in numeric_keypad callbacks
    [display.rs, main.rs, sensors_1_0_0.rs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]
2026-03-25 Add backend-to-UI sync support to TestHarness (#5)
    * Add backend-to-UI sync support to TestHarness
    * Replace sync-only tests with full roundtrip tests
    Convert test_sync_device_config_to_ui and test_sync_sensor_readings_to_ui
    into four roundtrip tests that exercise the complete loop:
    invoke_callback → dispatch_all → sync_to_ui → assert UI globals.
    Covers tank size, temperature display unit, pump enable, and sensor config.
    ---------
2026-03-25 Reduce test boilerplate and add make UI -> backend tests do the full round trip (#6)
    * Reduce test boilerplate with mock_ctx! macro and add full roundtrip assertions
    - Add mock_ctx! macro that replaces ~7 lines of context setup with 1 line
    - Bundle sync_to_ui() into dispatch_all() so every test gets the full
    callback -> dispatch -> sync roundtrip automatically
    - Add frontend (UI global) assertions to all existing tests alongside
    the backend state assertions
    - Remove dedicated test_roundtrip_* tests since all tests are now
    roundtrip tests
    - dispatch_all() now takes &mut self instead of &self
    * Derive pump index and number from D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
